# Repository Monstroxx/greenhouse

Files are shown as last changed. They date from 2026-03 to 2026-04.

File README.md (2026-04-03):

# Greenhouse Hexaplant

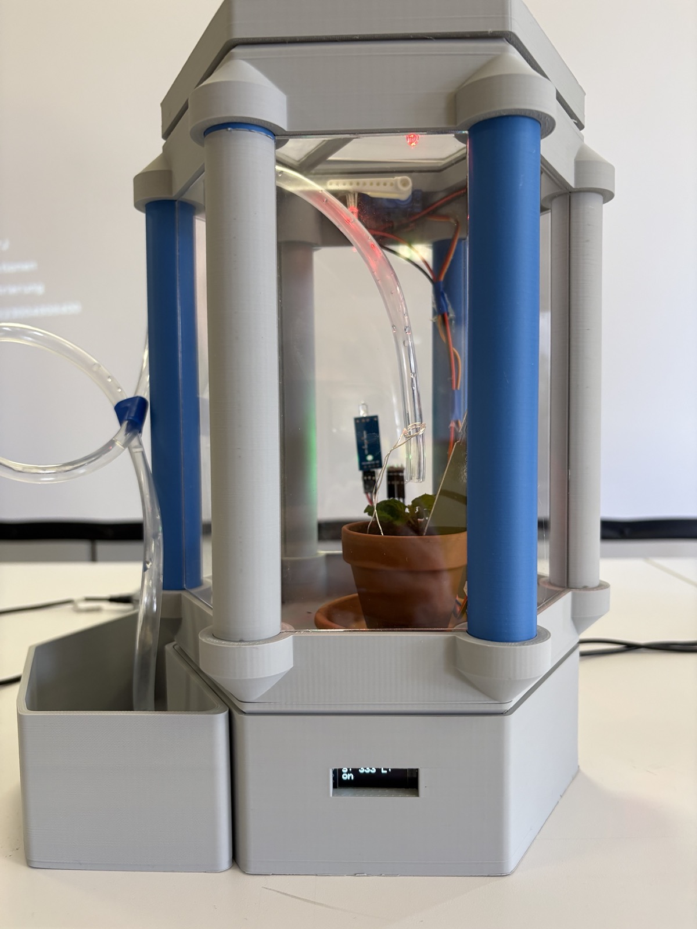
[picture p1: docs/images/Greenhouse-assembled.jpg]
Assembled Greenhouse


A smart greenhouse prototype developed as part of the **Erasmus 2026** exchange program between German and Spanish students. The system uses an Arduino Nano to automate plant care by monitoring environmental conditions and responding in real time.

---

## Table of Contents

- [Overview](#overview)
- [Extended Documentation](#extended-documentation)
- [Features](#features)
- [Bill of Materials](#bill-of-materials)
- [Wiring](#wiring)
  - [Pin Mapping](#pin-mapping)
  - [Motor Circuit](#motor-circuit)
- [Assembly](#assembly)
  - [3D Printing](#3d-printing)
  - [Laser Cutting](#laser-cutting)
- [Software](#software)
  - [Dependencies](#dependencies)
  - [Project Structure](#project-structure)
- [Flashing](#flashing)
- [How It Works](#how-it-works)
- [Credits](#credits)
- [License](#license)

---

## Overview

The greenhouse monitors soil moisture, ambient light, temperature, humidity, and barometric pressure. Based on sensor readings it can:

- **Water plants automatically** when the soil is too dry.
- **Open a window** via servo motor when humidity is too high.
- **Activate RGB lighting** when it gets dark.
- **Display sensor data** on a built-in OLED screen.

The enclosure is designed to be assembled from 3D-printed and laser-cut parts so it can be transported easily (e.g. on an airplane).

---

## Extended Documentation

For a detailed, professional breakdown of the project's engineering, collaboration, and specific mechanisms, please consult the extended documentation files in the `docs` folder:

* [01 Project Overview](docs/01_Project_Overview.md)
* [02 Features and Theory](docs/02_Features_and_Theory.md)
* [03 Components and Hardware](docs/03_Components_and_Hardware.md)
* [04 Planning and Collaboration](docs/04_Planning_and_Collaboration.md)
* [05 Software Architecture](docs/05_Software_Architecture.md)
* [06 Difficulties and Conclusions](docs/06_Difficulties_and_Conclusions.md)
* [07 Future Improvements](docs/07_Future_Improvements.md)

You can also browse the [Main Directory Documentation Index](docs/README.md) for a summary of these topics.

---

## Features

| Feature | Description |
|---|---|
| Automatic irrigation | A soil moisture sensor triggers a relay-driven water pump when the soil drops below a configurable threshold. |
| Light detection | A photodiode detects darkness and activates an RGB LED with a smooth color-fading effect. |
| Climate monitoring | A BME280 sensor measures temperature, humidity, and barometric pressure. |
| OLED display | A 128×32 I²C OLED shows live sensor readings. |
| Window control | A servo motor opens and closes a greenhouse window based on environmental conditions. |

---

## Bill of Materials

| # | Component | Quantity | Notes |
|---|---|---|---|
| 1 | Arduino Nano (Rev 3.0) | 1 | ATmega328P, CH340 USB |
| 2 | BME280 Breakout | 1 | Temperature, humidity, barometric pressure (I²C) |
| 3 | OLED Display 128×32 | 1 | SSD1306, I²C address `0x3C` |
| 4 | Capacitive Soil Moisture Sensor | 1 | Analog output |
| 5 | KY-019 5V Relay Module | 1 | Controls the water pump |
| 6 | DC Water Pump | 1 | Driven via relay |
| 7 | Servo Motor (9g) | 1 | Window control |
| 8 | Photodiode Module | 1 | Digital output (dark/light) — TCRT5000 footprint¹ |
| 9 | RGB LED (common cathode) | 1 | |
| 10 | 220Ω Resistor | 3 | One per RGB channel |
| 11 | 9V Battery Pack | 2 | One for Arduino (VIN), one for motor circuit |
| 12 | Irrigation hose + fittings | 1 set | Included with pump kit |

> ¹ The TCRT5000 is used as a placeholder in the schematic. The actual module is a photodiode breakout with four pins: **VCC**, **GND**, **DO** (digital out), **AO** (analog out).

---

## Wiring

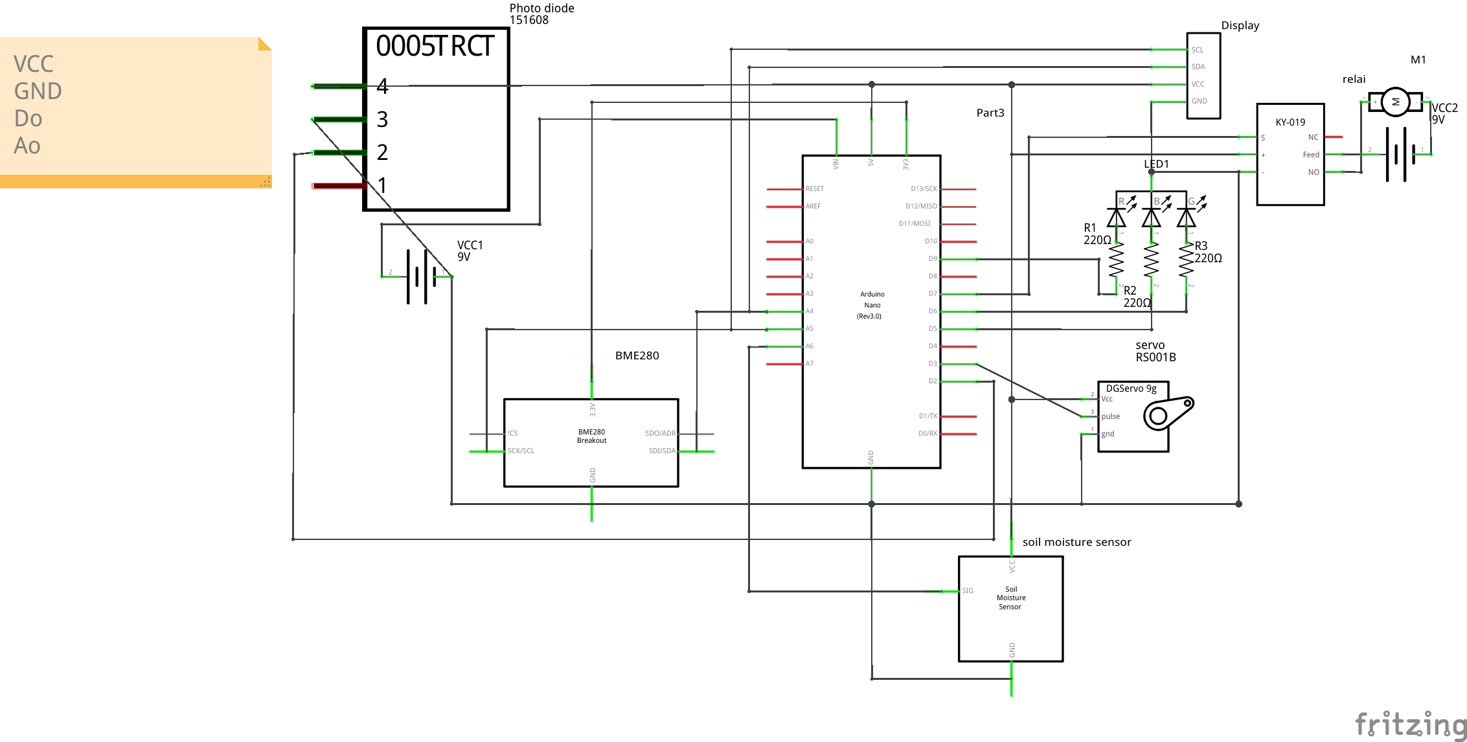
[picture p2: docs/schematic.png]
Wiring Schematic


### Pin Mapping

| Arduino Pin | Component | Component Pin |
|---|---|---|
| `D2` | Photodiode module | DO (digital out) |
| `D3` | Servo motor | Signal (pulse) |
| `D9` | 220Ω → RGB LED | Red anode |
| `D5` | 220Ω → RGB LED | Blue anode |
| `D6` | 220Ω → RGB LED | Green anode |
| `D7` | Relay module (KY-019) | S (signal) |
| `A4` | BME280 / OLED display | SDA |
| `A5` | BME280 / OLED display | SCL |
| `A6` | Soil moisture sensor | SIG |
| `5V` | Display, photodiode, soil sensor, relay, servo | VCC |
| `3V3` | BME280 | 3.3V |
| `GND` | All components | GND |
| `VIN` | 9V battery #1 | + |

### Motor Circuit

The water pump runs on a **separate 9V power supply** switched through the relay:

| From | To |
|---|---|
| 9V Battery #2 (+) | Relay COM |
| Relay NO | DC Motor pin 1 |
| DC Motor pin 2 | 9V Battery #2 (−) |
| 9V Battery #2 (−) | Common GND |

> The relay isolates the motor circuit from the Arduino's logic power, preventing voltage spikes from damaging the microcontroller.

---

## Assembly

### 3D Printing

Structural parts of the greenhouse are provided as **STL** files in the [`3D/`](3D/) directory. Print with standard PLA or PETG at 0.2 mm layer height.

### Laser Cutting

Panel and wall templates are provided as **SVG** files in the [`laser/`](laser/) directory. Designed for acrylic (Plexiglas) sheets.

> The greenhouse is designed with snap-fit / plug-in connections so it can be assembled and disassembled without tools for easy transport.

### Step By Step

1. Printing
  Print all needed Parts from [3D Printing](#3d-printing). You can also print the water tank extension but you can just take a bottle or cub.

2. Wiring
  Assemble the 3D Printed structure of the Greenhouse so you know where to put the sensors and the actors.

  Allways have a look on the wiring mentioned in [Wiring](#wiring). You need to connect the stuff to the arduino exactly like in our plan.
  
  The RGB LEDs needs to be in the plant tank and point to the plant.
  
  The servo needs to be glued on the Pillar Top, so it can open the Window with rotation. To get a longer arm we used [a model from Makerworld](https://makerworld.com/de/models/981832-servo-arms-horn-and-hook) (the 40mm one).

  The pump can be put into the tank extension or just into a water bottle. The pipe can be threaded through one of the holes provided in the Plant Base or Pillar Top.

  The sensors also needs to be put inside the plant tank. Just glue them where is practicable. Use the holes for wiring.

3. Code
  Flash the code found in [Flashing](#flashing). Please check if the servo is spining in the right direction. Please check if the variables are fitting your needs.

4. Glass
  You need a laser cutter for the glass and cut it like mentioned in [Laser Cutting](#laser-cutting).

3. Assemble
  Now you need to put the glass into the rails in the pillars to rotate them correctly. Then glue the Pillars to the bottom.
  On the top you need the two windows to glue on the Top Window Holder. The first gets glued completely onto one side. The second needs to be on the side with the slight dip. You only glue the second with a hinge into the slight dip.

  Put the Plant Base tight onto the Base and the Window can be put onto the Pillar Top and It can be easily lifted and removed.

---

## Software

### Dependencies

| Library | Source | Notes |
|---|---|---|
| **Adafruit GFX Library** | [GitHub](https://github.com/adafruit/Adafruit-GFX-Library) | Core graphics library for the display |
| **Adafruit SSD1306** | [GitHub](https://github.com/adafruit/Adafruit_SSD1306) | OLED driver |
| **Adafruit BusIO** | [GitHub](https://github.com/adafruit/Adafruit_BusIO) | I²C/SPI abstraction (dependency) |
| **Adafruit BME280** | [GitHub](https://github.com/adafruit/Adafruit_BME280_Library) | Climate sensor driver |
| **Servo** | [Arduino Docs](https://docs.arduino.cc/libraries/servo/) | Servo motor control |
| **Wire** | Built-in | I²C communication |
| **SPI** | Built-in | SPI communication |

Install all libraries via the **Arduino IDE Library Manager** or clone them into your `libraries/` folder.

### Project Structure

```text
greenhouse/
├── README.md                # Project documentation
├── LICENSE                  # MIT License
├── greenhouse.ino           # Main firmware source code
├── 3D/                      # 3D-printable parts (*.stl)
├── laser/                   # Laser-cut templates (*.svg)
└── docs/                    # Extended documentation
    ├── README.md            # Extended docs index
    ├── 01_Project_Overview.md
    ├── 02_Features_and_Theory.md
    ├── 03_Components_and_Hardware.md
    ├── 04_Planning_and_Collaboration.md
    ├── 05_Software_Architecture.md
    ├── 06_Difficulties_and_Conclusions.md
    ├── 07_Future_Improvements.md
    ├── images/              # Documentation images
    ├── Greenhouse Presentation.pptx # Project presentation
    ├── netlist.xml          # Fritzing netlist export
    ├── schematic.fzz        # Fritzing project file
    └── schematic.png        # Wiring schematic export
```

---

## Flashing

1. Install the [Arduino IDE](https://www.arduino.cc/en/software).
2. Connect the Arduino Nano via USB.
3. In **Tools → Board**, select **Arduino Nano**.
4. In **Tools → Processor**, select **ATmega328P** (or **ATmega328P (Old Bootloader)** if upload fails).
5. Select the correct **COM port** under **Tools → Port**.
6. Install all [dependencies](#dependencies) via **Sketch → Include Library → Manage Libraries**.
7. Open `greenhouse.ino` and click **Upload** (→).

---

## How It Works

```
┌──────────────────────────────────────────────────┐
│                  Arduino Nano                    │
│                                                  │
│  Soil Moisture (A6) ──► too dry? ──► Relay (D7)  │
│                                     └──► Pump ON │
│                                                  │
│  Photodiode (D2) ────► dark? ────► RGB LED       │
│                                     (D4/D5/D6)   │
│                                     └──► Fade FX │
│                                                  │
│  BME280 (I²C) ───────► read T/H/P                │
│                         └──► Display (I²C)       │
│                                                  │
│  Servo (D3) ─────────► humidity high?            │
│                         └──► Open window         │
└──────────────────────────────────────────────────┘
```

### Configuration

Key thresholds and timings are defined at the top of `greenhouse.ino`:

```cpp
// Soil moisture validation
#define MOISTURE_THRESHOLD 400 // From 0 to 400 = wet soil, Above 400 = dry soil

// Climate limits for window automated control
const int max_temp = 25;       // Open window if temp > max_temp
const int min_temp = 18;       // Close window if temp < min_temp
const int temp_margin = 2;     // Hysteresis margin
const int max_hum = 70;        // Open window if humidity > max_hum
const int min_hum = 50;        // Close window if humidity < min_hum
const int hum_margin = 5;      // Hysteresis margin

// Servo angles
const int window_close_pos = 90;
const int window_open_pos = 180;

// Update intervals (in milliseconds)
const unsigned long SENSOR_INTERVAL_MS = 1000;  // Measure sensors every 1s
const unsigned long DISPLAY_INTERVAL_MS = 3000; // Cycle display pages every 3s
const unsigned long DISCO_INTERVAL_MS = 10;     // Update LED colors every 10ms
```

---

## Credits

This project was developed as part of the **Erasmus 2026** program — a collaborative exchange between German and Spanish students and teachers, organized by the engineering office **IngGreen**.

Special thanks to all participants and mentors who contributed to the design, development, and documentation of this prototype.

---

## License

This project is licensed under the [MIT License](LICENSE).

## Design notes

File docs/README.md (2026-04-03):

# Extended Documentation Index

This directory contains the professional, detailed documentation for the Greenhouse project. Browse the sections below to understand the technical and organizational aspects.

- **[01 Project Overview](01_Project_Overview.md)**  
  High-level academic description of the systems, purpose, and final assembly of the greenhouse.

- **[02 Features and Theory](02_Features_and_Theory.md)**  
  Thorough explanations on how the irrigation loop, window hysteresis boundaries, and gamma-corrected RGB LED simulations operate.

- **[03 Components and Hardware](03_Components_and_Hardware.md)**  
  Details of every sensor (BME280, Photodiode, Moisture), actuator (Pump, Servo), and structure (3D-printed parts) alongside physical breadboarding images and Fritzing schematics.

- **[04 Planning and Collaboration](04_Planning_and_Collaboration.md)**  
  Breakdown of the 3-week Erasmus exchange using Agile/Scrum methods (Trello, Sprint stories) to coordinate between the German and Spanish team members.

- **[05 Software Architecture](05_Software_Architecture.md)**  
  Under-the-hood logic detailing why standard delays were bypassed in favor of dynamic `millis()` loop counters.

- **[06 Difficulties and Conclusions](06_Difficulties_and_Conclusions.md)**  
  A recap of the hardware delays (and the team's self-funded workaround) that severely constrained the build time.

- **[07 Future Improvements](07_Future_Improvements.md)**  
  Pathways for optimizing energy efficiency, integrating Wi-Fi IoT boards (ESP32), and establishing a Web UI.

> *Note: For the firmware logic itself, please refer directly to the root source file:* **[`../greenhouse.ino`](../greenhouse.ino)**

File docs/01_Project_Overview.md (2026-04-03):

# Project Overview

Assembled Greenhouse

The Greenhouse project is a smart, automated plant container engineered during the **Erasmus 2026** exchange program between German and Spanish students. Spanning a rigorous 3-week timeline, the objective was to construct an autonomous microclimate capsule that tracks critical environmental parameters and mechanically regulates the habitat without human intervention. 

## Prototype Sketch

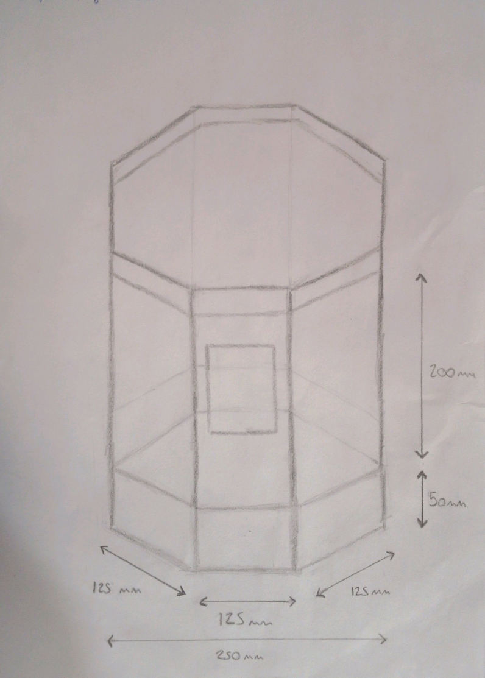
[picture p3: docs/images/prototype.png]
Initial Concept Sketch


The enclosure incorporates a sleek, modern design that is functionally optimized. It relies on an **Arduino Nano** microcontroller as the core logic unit and seamlessly integrates various digital and analog sensors. This provides real-time data on internal temperature, barometric pressure, air humidity, ambient light, and soil moisture. 

To react to these parameters, the greenhouse automatically executes mechanical and electronic tasks: watering the plants via a submerged dc-motor pump, adjusting physical ventilation by manipulating a window hinge with a servomotor, and activating an artificial RGB light cycle that transitions smoothly when the ambient light drops.

Designed to be both easily reproducible and modular, the greenhouse superstructure uses 3D-printed pillar joints and laser-cut transparent acrylic panes. The entire system can be snapped together, enabling disassembly for transport across international borders.

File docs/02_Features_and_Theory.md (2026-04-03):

# Features and Theory

The smart greenhouse provides four primary autonomous features designed to mimic a natural self-sustaining environment.

## 1. Automated Irrigation

Irrigation represents the core critical function of a greenhouse. The system continuously polls an analog soil moisture sensor placed deep within the plant substrate.
By averaging 100 consecutive analog readings to mitigate random noise spikes, the Arduino derives a reliable moisture score ranging from 0 (heavily saturated) to values exceeding 400 (very dry).
When the averaged value breaches the defined `MOISTURE_THRESHOLD` (set at 400), the logic triggers a digital output. This activates a heavy-duty relay running on an isolated 9V circuit, powering a submerged DC water pump until the measured soil saturation satisfies the established target, resulting in continuous hands-free watering.

## 2. Climate Monitoring and Window Ventilation

Ambient climatic shifts can stress plants quickly, so internal temperature, humidity, and barometric pressure are gathered via high-precision I2C communications utilizing a BME280 sensor breakout.
To prevent the rapid toggling of the greenhouse window (a continuous open-close loop known as "chattering" that could burn out the servo motor), the software incorporates **hysteresis** logic.
- Variables like `max_temp`, `min_temp`, `max_hum`, and `min_hum` are defined with additional variable margins (`temp_margin`, `hum_margin`). 
- If the temperature crosses above the maximum plus the margin, the servo motor mechanically drives the acrylic roof window open (`window_open_pos` set to 90 degrees) to allow external air circulation.
- Conversely, the window will not close again until the conditions drop below the minimum boundary minus its respective margin (`window_close_pos` set to 180 degrees), ensuring smooth and intentional ventilation cycles without motor fatigue.

## 3. Reactive Lighting Simulation

Natural sunlight cycles form the basis of photosynthesis. The module employs a digital photodiode detector calibrated via a physical potentiometer to identify a specific darkness threshold. When sunset occurs or artificial lighting drops to absolute zero, the Arduino identifies the `HIGH` digital state.
The MCU reacts by initializing a hardware PWM (Pulse Width Modulated) looping function. Rather than merely turning on the RGB LED starkly, it uses a non-blocking mathematical conversion loop (`hsvToRgb`). This loop slowly advances the hue angle over a timeframe of fractional milliseconds, continuously calculating RGB values while applying Gamma Correction, ensuring a smooth visual transition across the light spectrum to supplement the plant's light diet aesthetically.

## 4. Diagnostics Display

While automation negates the need for manual check-ups, monitoring system health is critical. To this end, an organic light-emitting diode (OLED) panel interfaces directly alongside the BME280 over the same two-wire interface (I2C) using the address `0x3C`.
Every 3000 milliseconds, the loop pushes an updated hardware snapshot to the 128x32 screen buffer—alternating automatically between displaying the latest temperature/humidity readings and the real-time digitized soil/light variables.

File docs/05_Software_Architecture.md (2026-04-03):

# Software Architecture

The software logic orchestrates the `greenhouse.ino` source code sequentially over hardware loops inside the Arduino IDE, primarily utilizing non-blocking polling mechanics instead of standard delays.

## Dependencies

The source relies on universally standard libraries initialized over `SPI.h` and `Wire.h`:
- `Adafruit_GFX.h` / `Adafruit_SSD1306.h` for drawing characters, allocating memory strings, and hardware scrolling onto the tiny OLED screen block.
- `Adafruit_BME280.h` / `Adafruit_Sensor.h` for environmental value interpolation over precise I2C data packets.
- `Servo.h` to transmit mapped pulse-width signals (`0-180`) into physical mechanical motion on the structural hinges.

## System Logic

Inside `loop()`, the software avoids `delay()` commands because stopping execution prevents time-critical processes—such as LED fading (`discoStep()`) and immediate sensor polling—from achieving synchronization.

### Sensor Cycles
Instead of waiting out an interval natively, the `sensors` rely on an `unsigned long SENSOR_INTERVAL_MS = 1000;`. Every calculated second, the program measures the real-time threshold and immediately determines output logic.

- If `temp > max_temp - temp_margin`, `window_angle = window_open_pos;`, enforcing safety against "chattering" or bouncing conditions via hysteresis margins (`temp_margin = 2`).
- A `measureandpour()` handler reads `soil_moisture_pin` 100 consecutive times into a `long` array. The average output mitigates random voltage spikes. If this consolidated `soil` reading exceeds `MOISTURE_THRESHOLD` (400), it energizes `digitalWrite(rele_pin, LOW)` and pulls the pump contacts together.

### Aesthetics and Color Space
When the sensor on `D2` outputs `HIGH`, a state machine toggles `discoEnabled = true`. The program then iterates every `10` milliseconds, running the `discoStep()` sequence mathematically, continuously converting `hsvToRgb` from Hue 0.0f to 1.0f on a fractional loop. Additionally, the RGB output integers interface with a non-linear `gammaCorrect(int value)` multiplier (applying a mathematical power of 2.2), ensuring smooth human-eye transition capabilities for lower-cost diodes.

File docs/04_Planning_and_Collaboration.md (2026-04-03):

# Planning and Collaboration

The Erasmus 2026 exchange program was structured around a strict 3-week timeline requiring rapid prototyping, clear communication, and efficient task division among international students. To handle the complexity of language and specialized engineering tasks, the team adopted the Agile development methodology, specifically Scrum.

## Project Management and Roles

The development group utilized shared digital tools to manage resources, code bases, and daily tasks:

- **Rafa Lebrón**: Operated as the Scrum Master, ensuring the team adhered to the Sprint Backlog and resolving blockers before they affected development times.
- **Alex**: Functioned as the Designer, translating conceptual structures into concrete CAD components.
- **TagerTi**: Acted as a Programmer, responsible for the initial firmware loops and hardware prototyping.
- **Monstroxx**: Served as a Programmer, integrating sensor logic, debugging loop iterations, and establishing the final software stack.

## Collaboration Tools

A robust toolchain enabled seamless tracking and execution:
- **Trello (Kanban)**: Maintained for continuous integration of User Stories (such as "Greenhouse Design," "Microcontroller Installation," and "Display Sensor Data") against active `Sprint` cycles. 
- **Google Drive**: Served as the centralized repository for shared documents, CAD prototypes, and weekly reports.
- **GitHub**: Ensured version control for the `greenhouse.ino` source code and overarching documentation.
- **Pytha and Onshape**: Supported parametric 3D modeling and laser-cutting exports (`.svg`) for the physical superstructure.
- **Fritzing**: Used collaboratively to verify electrical boundaries and draft the system's `netlist.xml` before soldering commenced.
- **Arduino IDE**: Handled the native C++ compiling and flashing cycles onto the ATmega328P.

## Milestone Breakdown

### Week 1: Ideation and Structuring
The first week focused entirely on architectural scoping. The team successfully created conceptual blueprints, established the Agile Kanban boards on Trello, integrated shared Drive folders, and visited CosmoCaixa for thematic inspiration. By Thursday, precise component locations were mapped using Fritzing.

### Week 2: Initial Implementation and Logistics
Hardware realization began by translating 3D models into PLA prints via the school's facilities. The Scrum Master and Designer pushed to finalize baseplate topologies. Despite significant delays caused by the late delivery of primary electrical systems (which did not arrive until Wednesday), the Programmers adapted swiftly. By Thursday, initial sensor integration (`OLED`, `BME280`, `Moisture`, and `Photodiode`) alongside fundamental LED behaviors were reliably compiled. 

### Week 3: Final Assembly and Integration
The final days synthesized software and hardware. Actuators alongside the acrylic (Plexiglas) roof structures were cut out via the exported `.svg` files and assembled dynamically. Programmers validated the `Servo` ventilation system algorithms, ensuring sensors and effectors worked in tandem without deadlocks. The intensive exchange concluded on Thursday with a group presentation demonstrating the completely functional prototype system.

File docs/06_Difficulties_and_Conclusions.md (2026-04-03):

# Difficulties and Conclusions

While the Erasmus 2026 greenhouse project concluded successfully with entirely functional automation, the 3-week timeline experienced severe bottlenecks primarily rooted in hardware logistics and systemic discrepancies.

## Primary Challenges

- **Hardware Procurement and Delivery Delays**: The instructor placed an order for electronic components that ultimately proved inconsistent with the initial parts list drafted in Week 1. This discrepancy required rapid architectural recalibration. Additionally, these substitute parts did not arrive until Wednesday of the second week. By the time physical assembly and breadboard validation could begin, almost half of the development schedule had expired.
- **Self-Funded Component Replacement**: Instead of rewriting the software stack to accommodate the incorrect parts, the team decided to proactively order the correct actuators and logic components at their own expense. This ensured the hardware remained true to the initial design but added further time pressure to the development cycle.
- **Physical Assembly Compression**: Due to the cascading delays, finalizing the 3D prints (Pillars, Bases) and laser-cutting the Plexiglas sections (Roof, Windows) was compressed heavily into the remaining days of Week 3, leaving minimal margins for error. The glass mounting and servo alignments on the `Pillar Top` required particular mechanical exactness that was difficult to iterate within hours.

## Conclusions

Despite encountering severe hardware delivery delays, incorrect components, and a heavily compressed testing phase, the development team leveraged effective Scrum paradigms, modular design, and robust coding principles to complete all features.
The automated irrigation logic functions reliably alongside the complex BME280 hysteresis cooling cycle, while aesthetic flourishes—like the gamma-corrected RGB LED sequencing—demonstrate professional execution. The outcome validated the collaborative ability of the Spanish and German teams and provided excellent hands-on mechanical and electrical insight.

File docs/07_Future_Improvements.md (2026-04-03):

# Future Improvements

While the current implementation covers every planned feature for a smart greenhouse—soil moisture readings, climate response, and ambient lighting—future models possess immense room for further expansion.

## Microcontroller Migration (IoT Focus)
A critical limitation of the Arduino Nano ATmega328P is its lack of wireless connectivity. A fundamental upgrade involves replacing it with a Wi-Fi-enabled System on a Chip (SoC), such as the **ESP32** or **ESP8266**. This would enable remote monitoring, long-term historical data graphing for plant vitality analysis, and mobile push notifications for water tank reservoirs.
In parallel, establishing a mobile-friendly **Web UI** (User Interface) could display live parameters and toggle manual intervention via simple HTTP requests.

## Modularity and Energy Efficiency
- **Autonomous Power Structures**: Replacing the 9V disposable batteries with rechargeable Lithium-Ion standard (18650) cells and solar panels on the roof could dramatically increase the sustainability of the system over the long term.
- **Deep Sleep Cycles**: Instead of constant non-blocking loops, adapting the system to place the microcontroller and BME280 into a deep sleep, waking periodically to ping the moisture inputs or environmental logic, could prolong life exponentially.
- **Water Level Sensor**: Installing an ultrasonic or float sensor strictly inside the water tank could interrupt the `digitalWrite(rele_pin, LOW)` command and generate an alarm to prevent the pump from "running dry" and potentially sustaining thermal damage.

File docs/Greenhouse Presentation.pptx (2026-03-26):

## Hexaplant

Jonas, Rafa, Alex, Timon

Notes: Alex

## Modern Design

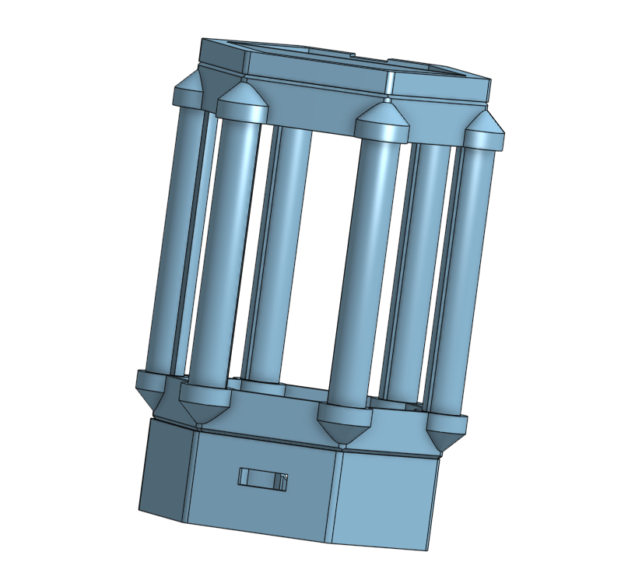
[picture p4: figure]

- Modular
- Simple parts
- Easy to assemble

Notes: Alex

## The Parts - 5 Pieces

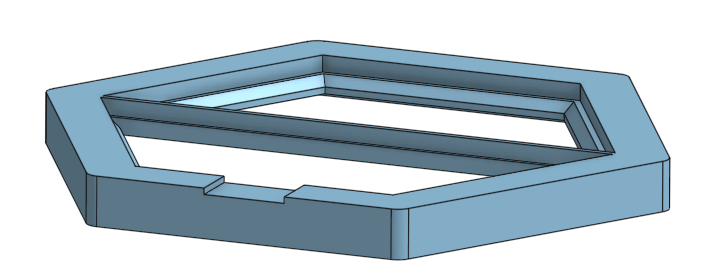
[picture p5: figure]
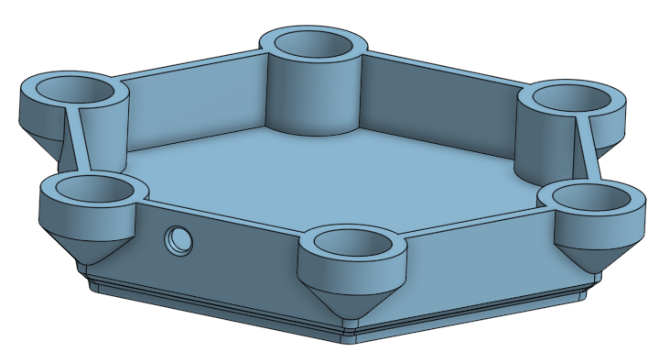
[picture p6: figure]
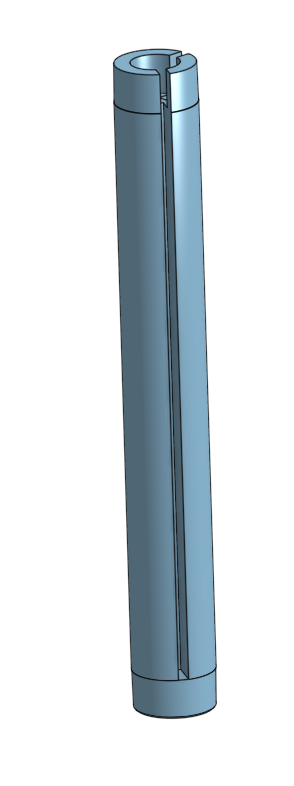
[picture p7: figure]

Pillar

Plant Base

Window Holder

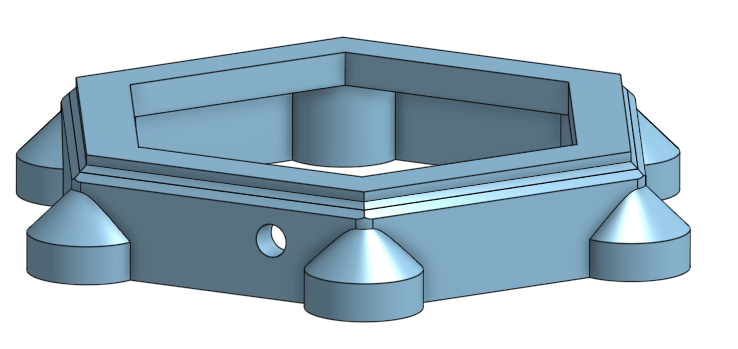
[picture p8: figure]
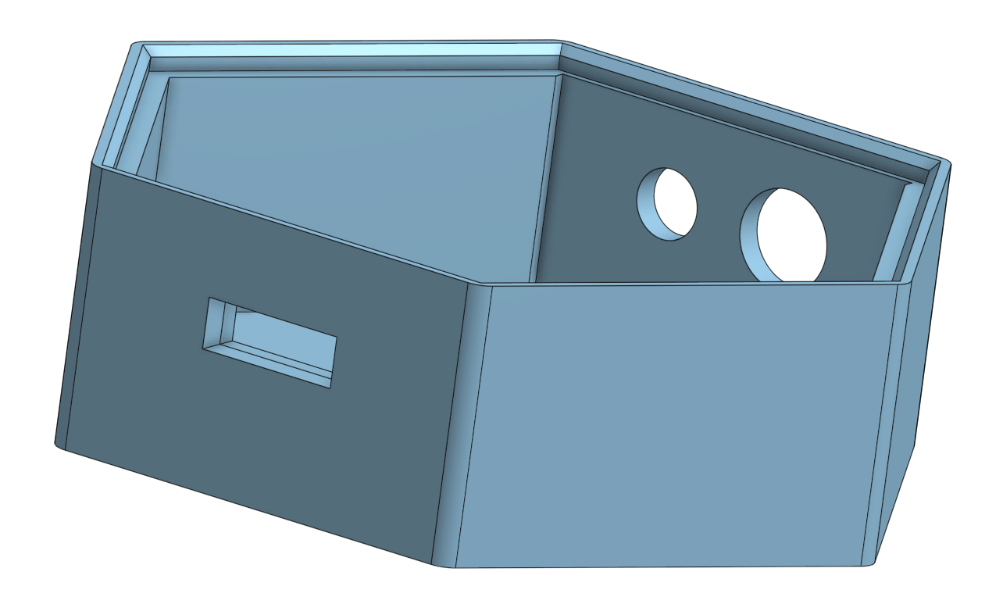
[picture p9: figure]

Base

Pillar Top

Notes: Timon

## Extension

- Provided Water tank.
- Other Extensions possible
that fit perfectly on the shape.

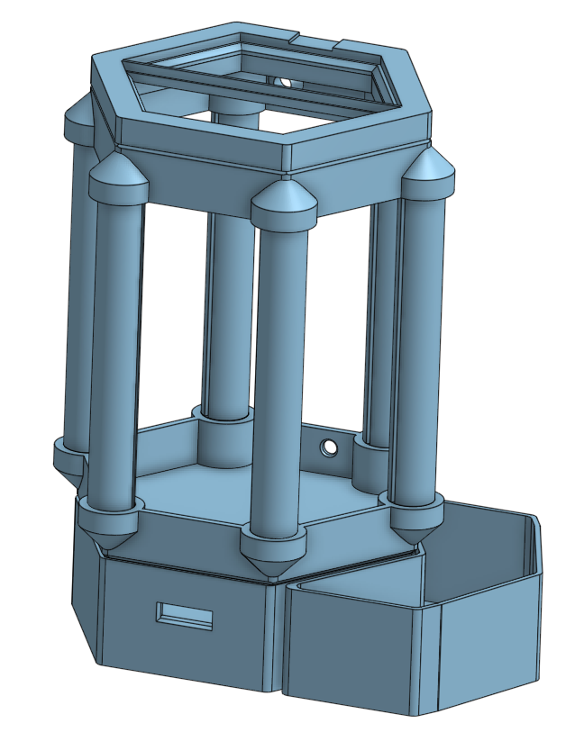
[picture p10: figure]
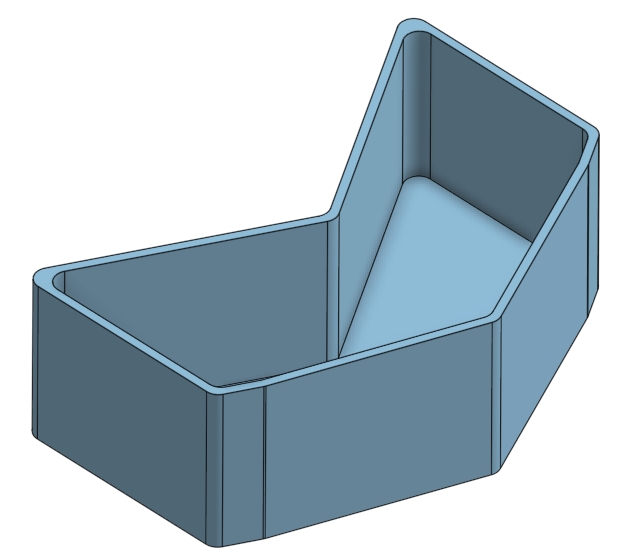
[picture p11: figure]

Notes: Timon

## Electronics


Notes: Jonas

## Features

- Display with window
  - Temperature
  - Humility
  - Soil messurement
  - Light level
- Pump
  - Automatic watering system
  - Water tank
- Window
  - Opens if to hot
  - Closes if to cold

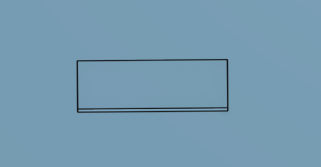
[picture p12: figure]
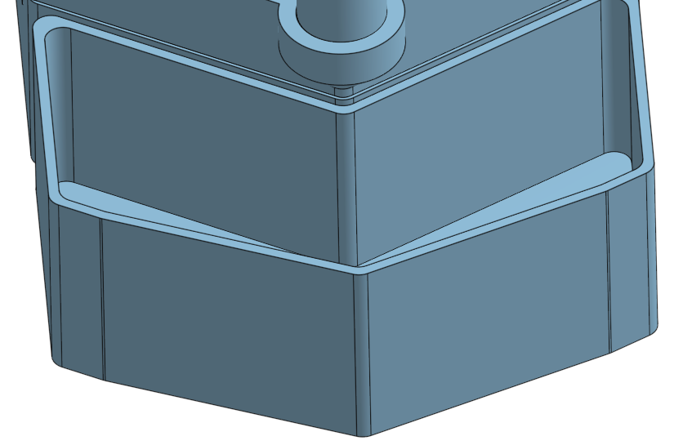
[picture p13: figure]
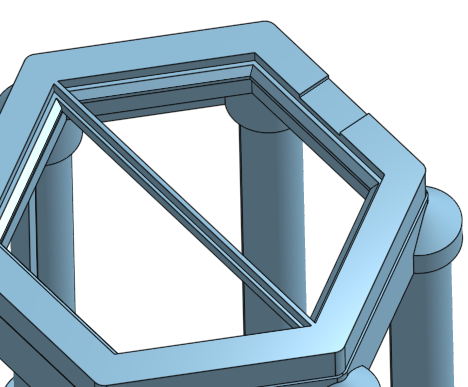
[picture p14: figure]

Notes: Jonas

## Assembly

- Print all required parts
- Assemble structure and wire components (see README.md (https://github.com/Monstroxx/greenhouse) → Assembly → Step By Step)
- Flash code and verify functionality
- Prepare and insert glass panels
- Complete final assembly

You can find the instructions at https://github.com/Monstroxx/greenhouse

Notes: Rafa

## In Action

- See it in real live

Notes: Rafa

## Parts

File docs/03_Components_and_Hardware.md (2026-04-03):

# Components and Hardware

The prototype employs multiple standalone input/output elements and runs natively on the Arduino Nano framework to leverage its robust digital, analog, I2C, and PWM capabilities.

## Microcontroller Stack

- **Arduino Nano Rev 3.0**: An ATmega328P microcontroller with an integrated dual-in-line package for breadboards and custom prototyping. Built-in pull-up resistors and a CH340 USB-to-serial converter form the backbone of the greenhouse logic functions.
- **Organic LED (OLED) 128x32**: Based on the versatile SSD1306 controller and operating over an I2C multi-drop topology (Address `0x3C`). The display shares the `SDA` (`A4`) and `SCL` (`A5`) pins and a stable `5V` logical supply to push 128x32 matrix characters effectively.

## Environmental Sensors

- **BME280 Breakout Module**: A precision component built predominantly by Bosch for environmental monitoring applications. Due to its I2C communication logic, it connects parallel to the OLED. Due to its precise logic levels, the breakout needs `3V3` instead of the general `5V` ring. It calculates the `Temperature`, `Humidity`, and `Barometric Pressure`, feeding them reliably with only an address-select modification (`0x76`).
- **Capacitive Soil Moisture Probe**: Instead of resistive contacts that suffer rapid corrosion, this capacitive breakout assesses moisture via variations in the dielectric constant of the wet/dry soil across its PCB traces, connected to the analog input `A6`.
- **Light Detection (Photodiode)**: The digital port `D2` listens to this comparator IC. Internally, a photodiode picks up infrared spectrum fluctuations and outputs a logical state directly determined through a tiny calibration potentiometer.

## Actuators and Actors

- **Water Pump and Flow System**: Driven via a `KY-019` solid-state relay triggered from the `D7` digital port. Due to power demands, a completely isolated `9V` battery circuit interfaces the primary `COM` and `NO` (Normally Open) relay terminal directly with the DC motor submerged beneath the primary acrylic layers.
- **Window Servo Motor (9g)**: Powered by internal PWM modulation on `D3`. A micro servo motor translates high-frequency rotational signals (mapped accurately from 0 to 180 degrees) via a 40mm fabricated mechanical arm that hinges the upper glass array manually without exceeding amperage thresholds on the main board.
- **RGB LEDs**: Driven over output lines `D9` (Red), `D6` (Green), and `D5` (Blue). Protective 220-ohm resistors ensure the integrated PWM sequences do not damage the diode junctions or microcontroller logic pins.

## 3D Printed Structural Components

The greenhouse housing is based on custom 3D-designed components intended for easy assembly, acting as structural pillars for the acrylic walls. Below are rendered overviews of these core elements:

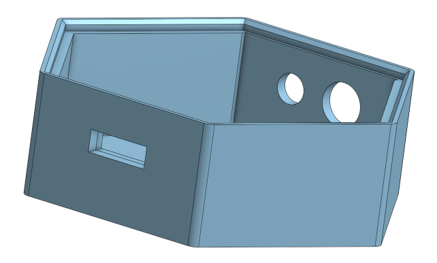
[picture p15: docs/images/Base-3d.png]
Base 3D Render
- **Base Platform**: 
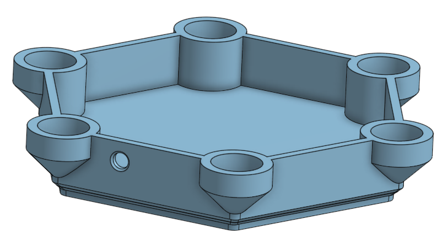
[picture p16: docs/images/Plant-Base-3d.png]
Plant Base 3D Render
- **Plant Tray / Hexabase**: 
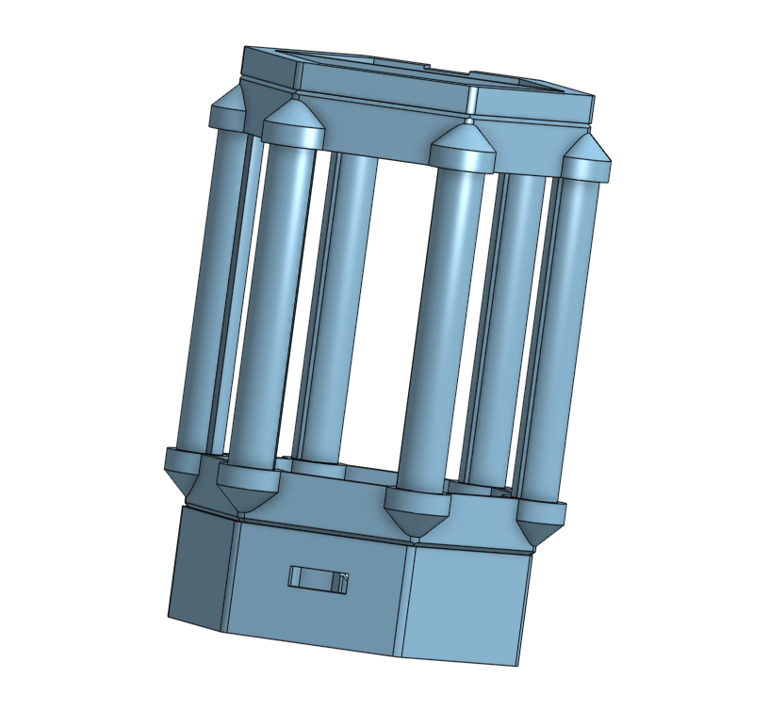
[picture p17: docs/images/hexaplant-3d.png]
Hexaplant 3D Render
- **Hexa-Frame Structural Core**: 
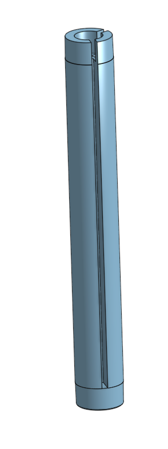
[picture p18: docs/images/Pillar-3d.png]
Pillar 3D Render
- **Corner Pillars**: 
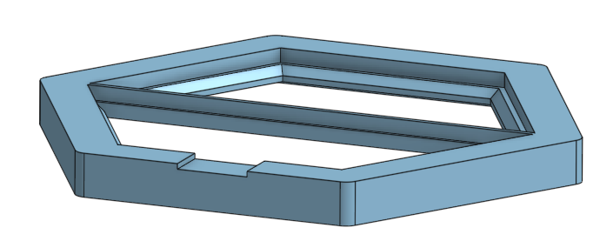
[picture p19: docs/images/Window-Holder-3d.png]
Window Holder 3D Render
- **Roof Hinge Support**: 

## Early Assembly

Prototyping required rigorous breadboarding and physical wire routing prior to final enclosure integration.

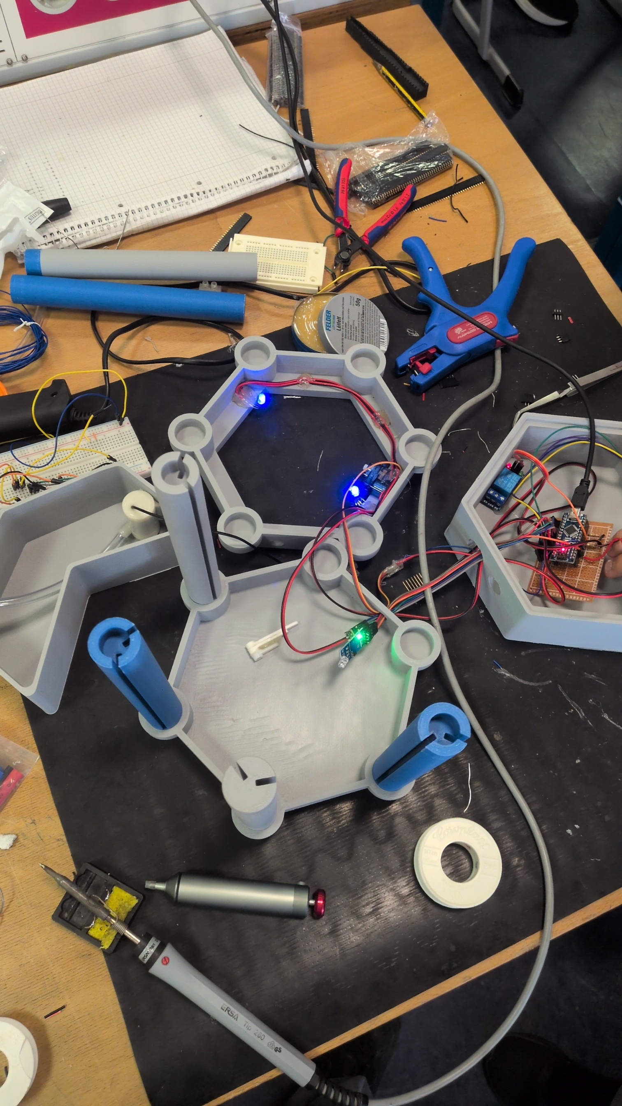
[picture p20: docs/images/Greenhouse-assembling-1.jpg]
Assembling the Hardware (1)

*Initial wiring with logic checks.*

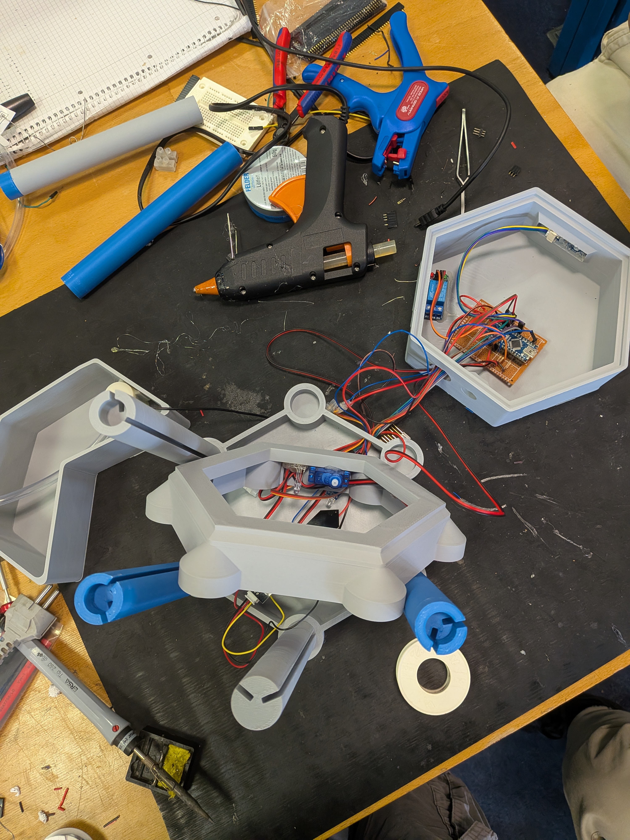
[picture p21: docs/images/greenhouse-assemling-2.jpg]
Assembling the Hardware (2)

*Fitting the electronics within the 3D printed base parameters.*

Fritzing Connectivity Schematic
*Digital schematic highlighting proper voltage references and pin layouts.*

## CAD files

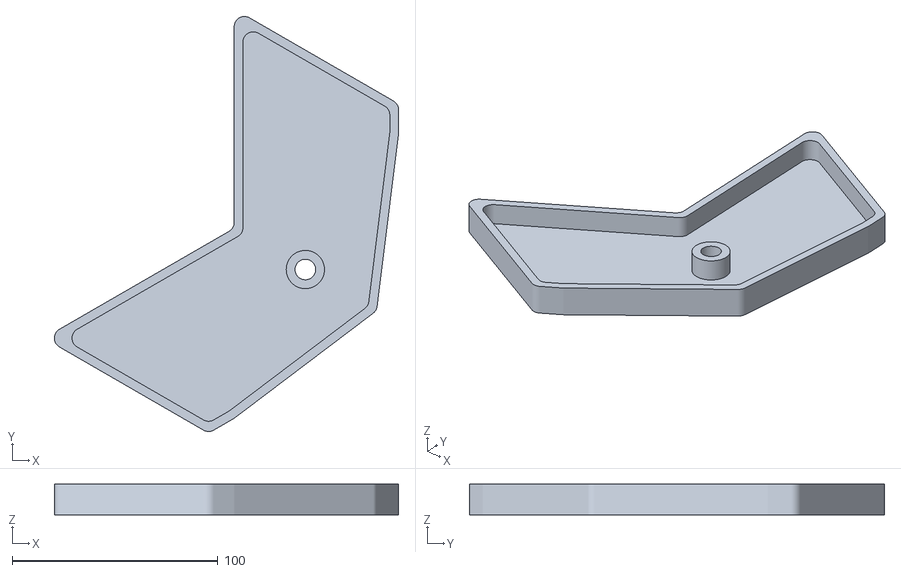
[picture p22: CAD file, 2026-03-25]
3D/Water Canister Extension Lid.stl
167.4 x 201.8 x 15.0

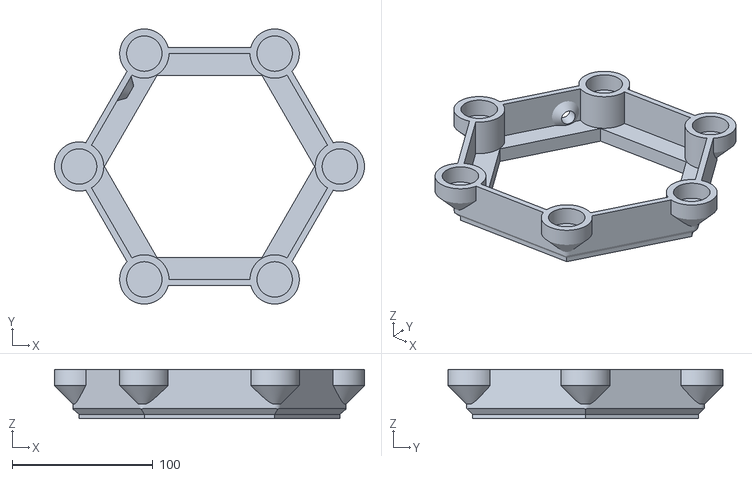
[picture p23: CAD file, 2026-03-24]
3D/Pillar Top.stl
220.2 x 195.4 x 35.0

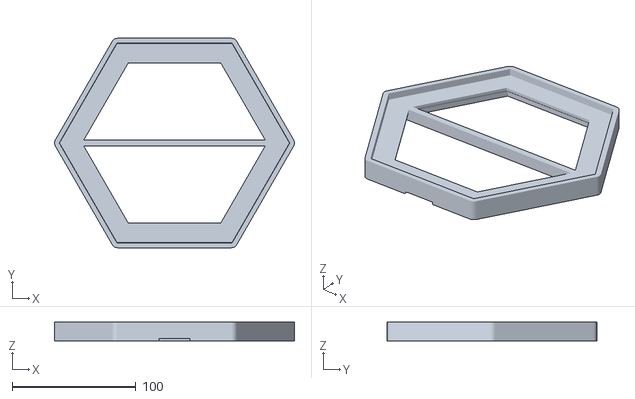
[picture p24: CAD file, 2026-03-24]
3D/Top Window Holder.stl
193.7 x 169.0 x 15.0

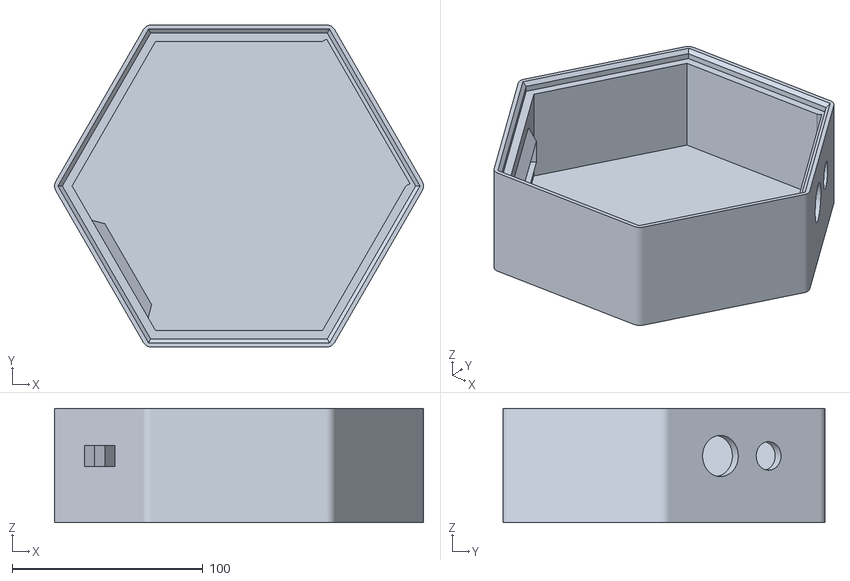
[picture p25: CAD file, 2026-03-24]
3D/Base.stl
193.5 x 168.9 x 60.0

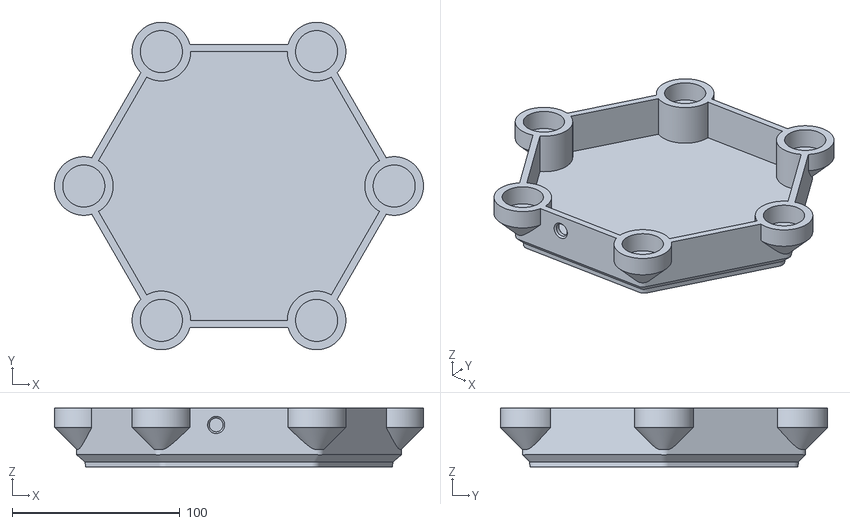
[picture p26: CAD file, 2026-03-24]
3D/Plant Base.stl
220.2 x 195.4 x 35.0

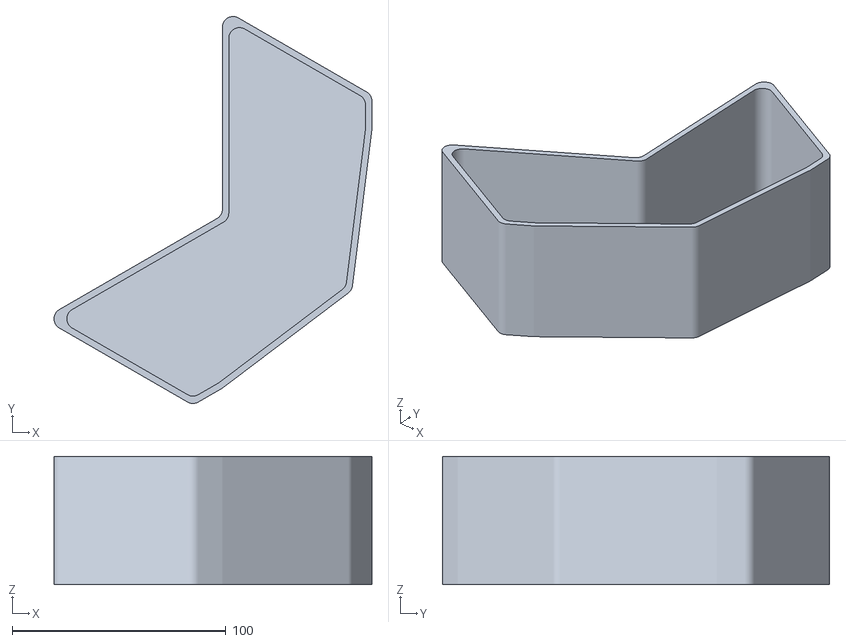
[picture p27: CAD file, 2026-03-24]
3D/Water Canister Extension.stl
148.8 x 181.1 x 60.0

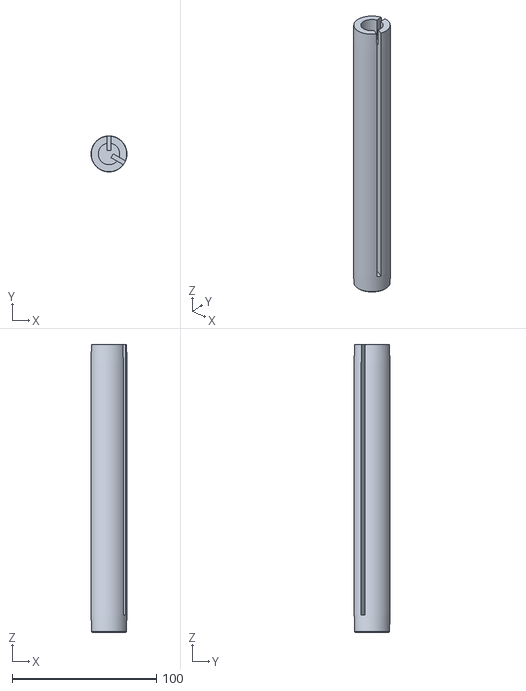
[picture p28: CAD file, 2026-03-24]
3D/Pillar.stl
25.0 x 24.9 x 200.0

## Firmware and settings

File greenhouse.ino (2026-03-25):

#include <SPI.h>
#include <Wire.h>
#include <Adafruit_GFX.h>
#include <Adafruit_SSD1306.h>

// Servo
#include <Servo.h> 

// BME 280 Sensor
#include <Adafruit_Sensor.h> 
#include <Adafruit_BME280.h>


#define SCREEN_WIDTH 128 // OLED display width, in pixels
#define SCREEN_HEIGHT 32 // OLED display height, in pixels
// On an arduino UNO:       A4(SDA), A5(SCL)
#define OLED_RESET     -1 // Reset pin # (or -1 if sharing Arduino reset pin)
#define SCREEN_ADDRESS 0x3C ///< See datasheet for Address; 0x3D for 128x64, 0x3C for 128x32
Adafruit_SSD1306 display(SCREEN_WIDTH, SCREEN_HEIGHT, &Wire, OLED_RESET);

// Defining soil moisture reading threshold
// From 0 to 400 - wet soil
// Above 400 - dry soil
#define MOISTURE_THRESHOLD 400

// Pins
const int redPin = 9;
const int greenPin = 6;
const int bluePin = 5;

const int light_sensor_pin = 2;
const int servoPin = 3;
const int rele_pin = 7;
const uint8_t soil_moisture_pin = A6;

// Settings
const int max_temp = 25;
const int min_temp = 18;
const int temp_margin = 2;
const int max_hum = 70;
const int min_hum = 50;
const int hum_margin = 5;

const int window_close_pos = 180;
const int window_open_pos = 90;

// TODO: globals -> local machen
const char* lighttext = "off";
int window_angle = 0;
long soil = 0;

float temp = 0.0;
float hum = 0.0;
float pres = 0.0;

bool discoEnabled = false;
bool displayPage = false;
float discoHue = 0.0f;

unsigned long lastSensorMs = 0;
unsigned long lastDisplayMs = 0;
unsigned long lastDiscoMs = 0;

const unsigned long SENSOR_INTERVAL_MS = 1000;
const unsigned long DISPLAY_INTERVAL_MS = 3000;
const unsigned long DISCO_INTERVAL_MS = 10;

Servo WindowServo;
Adafruit_BME280 bme;

void setup() {
  Serial.begin(9600);

  // Start BME Sensor and check for errors
  if (!bme.begin(0x76)) // manchmal 0x77
  {
    Serial.println("BME280 not found!");
    while (1)
    {
      Serial.println("BME280 not found! Please restart");
      //throw 404;
    }
  }

  setupdisplay();

  pinMode(rele_pin, OUTPUT);
  digitalWrite(rele_pin, HIGH); // Pumpe aus beim Start

  pinMode(light_sensor_pin, INPUT);

  pinMode(soil_moisture_pin, INPUT);

  pinMode(redPin, OUTPUT);
  pinMode(greenPin, OUTPUT);
  pinMode(bluePin, OUTPUT);

  // Add Servo to WindowServo
  WindowServo.attach(servoPin);
  window_angle = window_close_pos;
  WindowServo.write(window_angle);
  delay(2000);
}

void loop() {
  unsigned long now = millis();

  if (now - lastSensorMs >= SENSOR_INTERVAL_MS) {
    lastSensorMs = now;

    // Read BME 280 Sensor
    temp = bme.readTemperature();
    hum = bme.readHumidity();
    pres = bme.readPressure() / 100.0; // hPa

    // Window management
    if (temp > max_temp - temp_margin || hum > max_hum - hum_margin)
    { // To hot or too humid
      window_angle = window_open_pos;
    }
    else if (temp < min_temp + temp_margin || hum < min_hum + hum_margin)
    { // To cold or too dry
      window_angle = window_close_pos;
    }

    WindowServo.write(window_angle);
    measureandpour();
    lightcontrol();
  }

  if (discoEnabled && (now - lastDiscoMs >= DISCO_INTERVAL_MS)) {
    lastDiscoMs = now;
    discoStep();
  }

  if (now - lastDisplayMs >= DISPLAY_INTERVAL_MS) {
    lastDisplayMs = now;
    displayPage = !displayPage;

    if (!displayPage) {
      showtext("S: " + String(soil) + " L: " + String(lighttext), false);
    } else {
      showtext("T: " + String(temp, 1) + " H: " + String(hum, 1), false);
    }
  }
}

void setupdisplay(void) {
  // Wait for display
  delay(500);

  // SSD1306_SWITCHCAPVCC = generate display voltage from 3.3V internally
  if(!display.begin(SSD1306_SWITCHCAPVCC, SCREEN_ADDRESS)) {
    Serial.println(F("SSD1306 allocation failed"));
    for(;;); // Don't proceed, loop forever
  }

  delay(2000); // Pause for 2 seconds
  // Clear the buffer
  display.clearDisplay();
  display.display();
}

void measureandpour(void) {
  soil = 0;
  for (int i = 0; i < 100; i++) {
    soil += analogRead(soil_moisture_pin);
  }
  soil = soil / 100;

  // Print the sensor reading values
  Serial.print("Soil moisture sensor value: ");
  Serial.println(soil);

  if (soil > MOISTURE_THRESHOLD) {
    // Turn on the water pump
    digitalWrite(rele_pin, LOW);
  } else {
    // Turn off the water pump
    digitalWrite(rele_pin, HIGH);
  }
}

void lightcontrol(void) {
  int light = digitalRead(light_sensor_pin);
  if (light == HIGH){ // in front of it
    lighttext = "on";
    discoEnabled = true;
  }
  else{
    lighttext = "off";
    discoEnabled = false;
    setColor(0,0,0);
  }
  Serial.print("Light sensor value: ");
  Serial.println(lighttext);
}

void showtext(String text, bool scroll) {
  display.clearDisplay();

  display.setTextSize(2); // Draw 2X-scale text
  display.setTextColor(SSD1306_WHITE);
  display.setCursor(0, 0);
  display.println(text);
  display.display();      // Show initial text

  if (scroll) {
    display.startscrollleft(0x00, 0x0F);
  }
}

void setColor(int redValue, int greenValue, int blueValue) // Only for high quality LEDs
{
  analogWrite(redPin, redValue);
  analogWrite(greenPin, greenValue);
  analogWrite(bluePin, blueValue);
}

// Gamma-Korrektur
int gammaCorrect(int value)
{
  float normalized = value / 255.0;       // (0 - 255) to (0.0 - 1.0)
  float corrected = pow(normalized, 2.2); // Flat curve to Exponentially like curve
  return (int)(corrected * 255.0 + 0.5);  // Back to (0 - 255)
}

// Setzt die LED direkt (mit Gamma)
void setCorrectedRgb(int r, int g, int b) // Use for new LEDs
{
  analogWrite(redPin, gammaCorrect(r));
  analogWrite(greenPin, gammaCorrect(g));
  analogWrite(bluePin, gammaCorrect(b));
}

// HSV -> RGB
void hsvToRgb(float h, float s, float v, int &r, int &g, int &b)
{
  int i = int(h * 6);
  float f = h * 6 - i;
  float p = v * (1 - s);
  float q = v * (1 - f * s);
  float t = v * (1 - (1 - f) * s);

  float rf, gf, bf;

  switch (i % 6)
  {
    case 0:
      rf = v;
      gf = t;
      bf = p;
      break;
    case 1:
      rf = q;
      gf = v;
      bf = p;
      break;
    case 2:
      rf = p;
      gf = v;
      bf = t;
      break;
    case 3:
      rf = p;
      gf = q;
      bf = v;
      break;
    case 4:
      rf = t;
      gf = p;
      bf = v;
      break;
    case 5:
      rf = v;
      gf = p;
      bf = q;
      break;
  }

  r = rf * 255;
  g = gf * 255;
  b = bf * 255;
}

void discoStep() {
  int r, g, b;

  hsvToRgb(discoHue, 1.0, 1.0, r, g, b);

  // Optional: Prevents the sudden, harsh “flash-on” of blue light in low-cost LEDs
  if (b > 0 && b < 5)
    b = 5;

  setCorrectedRgb(r, g, b);

  discoHue += 0.001f;
  if (discoHue >= 1.0f) {
    discoHue = 0.0f;
  }
}

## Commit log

2026-03-18 finished automating pump and showing on the display
2026-03-19 fixed relay code
2026-03-19 implementet light sensor read
2026-03-19 added led on when its darc with dico mode
2026-03-20 edit project structure and added readme with lizense
    [schematic.fzz]
2026-03-20 fixed pmw pin for red led
    [schematic.fzz]
2026-03-21 Merged with Timons work
    - Servo
    - RGB LED
    - BME 280 sensor
2026-03-23 disco mode fix and show vars in display
    [greenhouse.ino]
2026-03-23 fix to many delays
    [greenhouse.ino]
2026-03-24 Work from 24/03
    - Step By Step in README
    - STL Files
    - Presentation start
    [Base.stl, Pillar Top.stl, Pillar.stl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]
2026-03-24 uploaded laser cutting files
2026-03-25 updated servo pos
2026-03-25 Water canister lid
    [Water Canister Extension Lid.stl]
2026-04-03 Fix image path for Fritzing Connectivity Schematic
